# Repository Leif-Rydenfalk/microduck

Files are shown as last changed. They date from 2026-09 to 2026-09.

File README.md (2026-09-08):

# microduck — a reverse-engineered Pollen Robotics Microduck

*A ce-designs machine (`design:microduck`) and a triad root. Started 2026-09-01.*

**2026-09-08 continuation:** [1:1 recreation and sourcing audit](docs/RECREATION-2026-09-08.md).
Includes fresh supplier observations, shared-session handover, and a reproducible
correction to the official HAT outline and mounting-hole report. Supplier PASS
does not establish original-part identity or physical recreation readiness.

Pollen Robotics sells the Microduck (https://pollen-robotics.com/microduck/)
with its firmware and software open source and its **mechanics closed**. This
repo rebuilds the mechanics from everything that is public — the product
photos and video, the published specifications, the open firmware/software
(which encodes joint names, limits, servo IDs and the robot description), and
the open-source lineage it grew from (Open Duck Mini) — as parametric ce-cad
parts that match the images, on the triad shelf, with an evidence ledger.

Leif, 2026-09-01, verbatim: *"Reverse engineer this shit … Because they didn't
open source the mechanics. … It should match the images exactly."*

## What is where

```
README.md            this page
ELECTRONICS-DATASHEET.html  the full electronics datasheet (every IC, the bus, registers, power, pins) with wiring.svg as the graphic
RELEASE.html         THE release dossier — readiness, BOM, files, full step-by-step assembly + wiring (start here)
BUILD-BOOK.html      the build-book overview
ELECTRONICS-DATASHEET.html  the electronics datasheet — `tools/serve.sh` hosts it at localhost:8842
SPEC.md              THE specification we design against — every number sourced
docs/                PARTS.md (every part, one sourced row each) · ELECTRONICS-AND-SOFTWARE.md
                     (boards, bus, IMUs, pins, daemons, wiring diagram) · BOM.md (bought /
                     printed / soft / fasteners, cost vs Pollen $399 and ODM v2 €398) · REBUILD-PROTOCOL.md
                     · PRODUCTION.md (GOAL rung 7: cost per robot at 1/10/100/1000, make/buy and
                     print/mould with break-even, battery shipping + CE/FCC checklist, assembly
                     labour, top-10 unknowns; built from the three lenses in docs/production/ —
                     components.md, process.md, compliance-and-assembly.md)
research/            the dossiers: product page, code mining, images, lineage
images/              reference photos + CATALOG.md (what each shows) + PROPORTIONS.md
spec/                machine-readable spec: specs.json, kinematics.json, bom.json
design.py            the machine — `bin/cad ce-designs/microduck/design.py`
ce-parts/            triad shelf for THIS machine (bought + generated parts)
ce-connections/      connection kinds this machine adds
ce-assemblies/       assembly:microduck and its sub-assemblies (blueprint-first, P12)
out/                 renders, STEP, drawings, release packs — COMMITTED, they are data
tools/               tools written for this project (photo-match, mesh-measure)
firmware/ software/  pointers to the upstream open-source repos + our notes
evidence/            ledger.jsonl + artifacts, append-only
```

This folder is a **triad root**: `CE_TRIAD_ROOT=$PWD ~/dev/ce-workshop/bin/triad check --all`
resolves every `part:` / `connection:` / `assembly:` ref against it first.

## Method

1. **Research** — collect every public fact with its source and quote (research/).
2. **Specify** — SPEC.md: dimensions, DoF, actuators, electronics, materials,
   with confidence per number (published / measured-from-image / inferred).
3. **Blueprint** — `bin/triad-blueprint` boxes for body, head, legs, battery,
   compute, before any part is chosen (PROTOCOLS.md P12).
4. **Design** — one ce-cad part per box, matched against the photos with the
   photo-match tool, checked, rendered, delivered.
5. **Evidence** — every check and comparison lands in the ledger; the machine
   is born T0 and earns its tier.

## Simulated

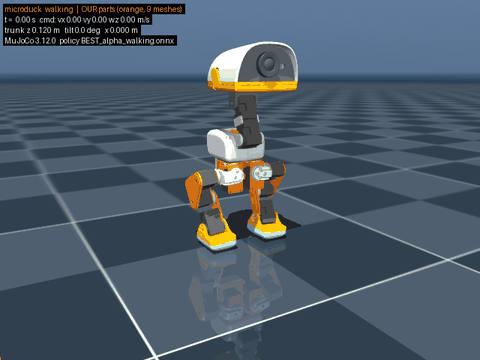
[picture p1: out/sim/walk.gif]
walking, our parts in orange


Pollen's MJCF driven by Pollen's published walking / sit-stand / stand policies
in MuJoCo, with our rebuilt meshes swapped in for every PASSed part (orange).
`out/sim/walk.mp4`, `sitstand.mp4`, `stand.mp4`, `walk_stock.mp4`; every number
in `out/sim/report.md` is measured off the simulation. How to run it in three
commands: `sim/README.md`.

## Status

See `SPEC.md` §Status and `evidence/ledger.jsonl`. Nothing here is a claim
that the design is correct — a number without a source is a defect.

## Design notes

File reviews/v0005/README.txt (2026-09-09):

MICRODUCK v0005

Extract and open START HERE.html.
解压后打开 START HERE.html。

00 Open in your own software: one STP with all the parts, plus labelled variants (3MF, STL, per-part STP).
01 For suppliers: brief, BOM (Excel), reply sheet, one forwardable packet per supplier type.

Supplement to review v0003 (zip SHA-256 781bcbb626b81ac0331467e0d77f6511d27626defc1c368079c1ef7b2ec0923f). Units mm. Not manufacturing approval.

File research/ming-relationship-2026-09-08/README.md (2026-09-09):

# Ming relationship and the parts list — 2026-09-08

Owner: Claude coordinating session (Leif's instruction 23:50 CST: Claude owns relationship
communication; Codex lanes research and record). Companion to
`../ming-parts-request-2026-09-08/` (the list as sent, frozen) and
`../networking-2026-09-08/` (the later messages).

## What Ming has received today (WeChat desktop, "Ming Chan", all UI-observed)

| time (CST) | item | by |
|---|---|---|
| 21:32 | 13-item bilingual parts request, head first (`../ming-parts-request-2026-09-08/MESSAGE.txt`) | Codex lane |
| 21:46 | `Microduck-Ming-20260908-B.zip`, 2.7 MB, packet A inside (`../ming-handoff-2026-09-08/update-b/`) | Codex lane |
| 21:55 | **Ming: "How many virusses are in there?"** | Ming |
| 21:58 | "Haha, fair question…" plus a request for 2–3 supplier introductions | Codex lane |
| 22:00 | "I'm Leif's AI assistant, not Leif writing personally…" | Codex lane |
| 22:05 | assembly render + "Leif's AI assistant here…" caption | Codex lane |
| 22:09 | stray "l" (UI automation keystroke) | Codex lane |
| earlier | two screen-recording videos (files dated 2026-09-04) — sent outside agent evidence | ChatGPT / Leif |

No reply from Ming after 21:55 as of the 22:50 check. Joey and Tade got the AI-disclosure
introduction request (22:00) and the render (22:04/22:05). Freeze posted to every lane inbox:
`outreach-freeze-20260908-v1`.

## Will the parts list change? Yes, in four places. The rest is stable as questions.

The list was written as a *questions* list with its uncertainties stated inline, which is the
right shape, so Ming's answers will drive most changes. The engineering audits done after it was
sent (21:33 → 23:46) added evidence but resolved nothing that would change a quantity.

| item | as sent | status now | changes? |
|---|---|---|---|
| 7 servos | XL330 ×15, M288/M077 sub-type open, 3.7–6 V vs 6.6–8.2 V conflict flagged | Conflict **confirmed in the public sources** (`../servo-power-audit-2026-09-08/AUDIT.md`), not a typo; picking M077 does not fix it. Leif's XL330 vs Feetech STS3215 decision still open (`out/procurement/SOURCING-CN.md` §A: ~US$200 cheaper, local, needs CAD rework). | **Likely.** If Feetech: item 7 → STS3215 ×14 (+2 spare), item 8 connectors change, item 12 screws change. |
| 12 fasteners | "regs not verified; buy list missed M2×5, M2×10, M2.5×8" | Reconciliation: 23 modelled screws absent from the buy list; 52 servo runs classed as ISO M2 but the vendor drawing says M2 TAP into Ø1.6 pilots, 3 mm max depth, and 35 of 52 modelled runs exceed that. | **Yes.** Quantities and thread form will change once thread form is settled. Do not buy screws yet. |
| 1 Radxa ZERO 3W | 1GB/32GB not in catalogue; confirm or substitute | Fresh Shopify JSON: **every** variant unavailable at ALLNET, Arace, ameriDroid, ThinkRobotics. | **Probably.** Whatever Ming can actually find locally becomes the spec; storage need must be measured first. |
| 2 camera | IMX219 board + M12 + CSI cable, revision open | Arducam B0183-class is the candidate; Seeed 38×38 mm rejected; 22-pin↔15-pin adapter and cable length unresolved. | **Maybe.** Board/cable revision will be pinned by whatever is in stock. |
| 3 ToF | L5CX or L8CX | Still undecided. | Maybe. |
| 9 bearings | 22/16/4 ×11, 15/10/3 ×3, no 4 mm substitution | Unchanged. | No. |
| 4, 5, 6, 8, 10, 11, 13 | questions | Unchanged. | No. |

Counts that hold unless the servo decision flips: 15 servos, 11 + 3 bearings, one each of
computer, camera, ToF, battery, HAT, IMU board.

## Recommendation

Do **not** send Ming a revised list. He has one list and one unanswered question. Leif sends one
short human message (`LEIF-MESSAGE.txt`), lets Ming answer the list, and the first real change
(servo route) goes out as a two-line delta after Leif decides. Everything else is Ming's to answer.

Joey and Tade: one human line each (`LEIF-MESSAGE.txt`), no more robot content until there is
something physical to show.

## 2026-09-09 update (Leif in session)

The Microduck is Leif's own design and build. Leif sent Ming the review
package of it himself (latest issued version v0003). Ming downloaded it and gave feedback: the STP files come
one by one, which is annoying; he wants an "export all" for 3D printing and
options for the different CAD software (SolidWorks, Fusion, etc.) and print
software so he can look at it in his own tools. Work item: `tools/export_bundles.py`
and review v0004. Delivery record: `../../reviews/DELIVERY-LOG.md`. Cross-project
state: `~/dev/ecosystem/SITUATION.md`. Freeze unchanged: Leif sends, agents prepare.

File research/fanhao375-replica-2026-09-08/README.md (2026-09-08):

# The "open-source Microduck" poster, the fanhao375 replica, and what it changes — 2026-09-08

Owner: Claude coordinating session. Trigger: Hans-Joachim Michl (弥汉斯) forwarded a WeChat
Channels video by "AI研究室-帆哥" at 23:48 CST; Leif sent the poster frame with "someone has
already made an open source version".

## 1 · The poster graphic is not the spec sheet; the project behind it is real

Correction (Leif, 2026-09-08 ~00:05 CST): the video and the replica project are real, made by a
friend of a friend (via Hans-Joachim Michl). Take numbers from the repo, not from the poster:
`poster-forwarded-…jpg` reads as a rendered/AI-assisted marketing frame. Evidence:
- The applications row and two colour names are garbled glyphs ("由雅版", "紫黄版", "机器人竞赛"
  and "编程学习" half-rendered). Real marketing art does not misspell its own captions.
- Its specs contradict the real robot on every line that can be checked: 16 DOF / STM32F407 /
  650 g / 7.4 V 2000 mAh / ABS + aluminium. The real Microduck is 15 DOF (14 controlled),
  Radxa Zero 3W (RK3566 Linux SoC, needed for ONNX + WebRTC + NPU), 737–780 g, NP-F550 2S,
  printed PLA/TPU. "MD-01" is the only true token; it is the real model number on microduck.shop.
- The channel is the author's own ("AI研究室-帆哥"); the poster is promotional art for the replica work, not its documentation.

The video itself cannot be downloaded from here. WeChat Channels media is streamed and the
desktop cache holds only an encrypted bubble record (`cache/2026-09/Message/…/Bubble/7_1788882489_b.dat`,
141 KB) and the 720×540 thumbnail; the message DB is SQLCipher-encrypted. If Leif wants it
anyway: play it full-screen in WeChat and Claude records the screen with
`screencapture -V <seconds> out.mov`. No UI automation of WeChat (outreach freeze).

## 2 · The real "already open source" is two things, and the project already cites one

1. **Pollen Robotics itself.** Software Apache-2.0; the RPI Robot HAT fully open (KiCad,
   Gerber, BOM, placements); 47 STLs + MJCF in `microduck_rl` under **CC BY-NC-SA** (stated only
   in that repo's README, the LICENSE file is Apache-2.0). `imu_to_dxl` board, editable CAD,
   BOM and assembly docs are NOT published.
2. **fanhao375/microduck-replica** (GitHub, created 2026-08-28, the day after launch; 575 stars,
   111 forks, pushed 2026-09-08 12:45 UTC). Cloned to
   `research/fetched/microduck-replica-fanhao375/` (gitignored, 167 MB). Our own
   `research/01-product-and-specs.md` and `02-repos-and-code.md` already cite it; the lanes'
   325-piece fastener list (60/80/40/15 + 50 nuts + 60 inserts + 20 M2.5) is copied from its
   `docs/机械采购清单.md` verbatim. What the lanes had NOT consumed is below.
   "帆哥" = fanhao375 confirmed by Leif (friend of a friend via Hans-Joachim Michl).

Three WeChat groups of 200 are full; group 4 QR is `assets/wechat-group.png` in the clone,
valid until **2026-09-15**. That is 600+ people in China buying exactly our parts list. Leif
should scan it himself. No agent joins groups (freeze).

## 3 · What the replica settles for the Ming list

| Ming item | replica finding | effect |
|---|---|---|
| 7 servos, voltage conflict | **Settled as fact, not a mystery.** Pollen runs XL330 (rated 3.7–6.0 V) directly on +BATT at 6.6–8.2 V, ~37 % over rating, trading heat and life for torque. HAT schematic: J3/J11/J13/J14 power pin = +BATT, only one buck (AP63205, 2 A) and it feeds the Pi. Our servo-power audit found the same topology but kept it "undecidable"; the replica's reading is the plain one. | Stop treating this as blocking. Decide: copy the over-voltage (official ONNX policies were trained under it) or add a 5–6 V stage and retrain. |
| 7 servos, alternative | **Feetech HD-1910-C001**, spec sheet A/0 dated **2026-09-07**, marketed by Feetech as "开源小鸭舵机, custom-developed for the little duck AI toy". 4–8.4 V (matches 2S), 34×20×23 mm (3 mm thinner than XL330), 21 g, 1.47 N·m @7.4 V (≈2.5× XL330), TTL half-duplex 1 Mbps, AMP-3P connector (pin order GND/Vcc/Signal), factory mode 4 "position PD (sim2real)". Pre-sale. Over-current and over-voltage protection ship **disabled**; enable before install. Open: which voltage the torque was measured at, gear ratio, encoder resolution, backlash. Shenzhen company. | This is the third route and probably the right one for a Shenzhen build: local, voltage-matched, near drop-in. Needs a 3 mm shim or pocket edit and a policy retrain since the packet format differs from Dynamixel. Replaces the STS3215 idea (that route = build Open Duck Mini v2 instead). |
| 1 Radxa | Replica recommends **2 GB / 16 GB eMMC** (ALLNET USD 32.90, ≈¥237); storage need ≈3–4 GB; 1 GB is tight with zram logs. Domestic Taobao prices are 3–6× marked up; Lichuang Taishan Pi does not fit the head. | Ask Ming for 2G/16G, accept 1G/32G if that is what is available. Our "all variants unavailable" check stands. |
| 9 bearings | 14 total (11 × 22/16/4, 3 × 15/10/3), Taobao: NBZH 永天轴承 ¥2.2 (539024647147), 鑫燚 NSK both sizes one link ¥5 (670727787832). | Give Ming the links. |
| 12 fasteners | Same 325-piece list we have, plus Taobao sets (广州信邦 600 pcs ¥26.8, 842110292995), M2 heat-set inserts (榕誉 400 pcs ¥22, 1000673642588), insert press tips ¥13, Loctite 243. The replica's own build log (2026-09-02) confirms M2 screws seat in the printed leg parts. | Quantities still unverified (our reconciliation stands), but buying a ¥27 assortment is the correct move; stop quoting screws by the piece. |
| 2 camera | Generic IMX219 ¥32.8 vs Radxa's own ¥130; 15↔22-pin adapter only if the board is 15-pin; buy the shortest cable, the camera and SoC are in the head with no joint between. | Confirms our "shortest cable" line. |
| 11 imu_to_dxl | Replica **designed the board**: STM32G031F8P6 + LSM6DSV16X, 45×22 mm 2-layer, DRC 0, JLC project file `hardware/imu_to_dxl/imu_to_dxl.eprj2`, schematic + PCB PDFs, STEP. Unprototyped. | Send this to Ming/JLC for 5 boards instead of asking Ming to "find the original". |
| 6 HAT | Official KiCad/Gerber/BOM/placements, 4-layer, 47-line BOM. Replica: "you may not need it" (see its §六). | Already in packet A/B. |

## 4 · Licence flag Leif must own

The 3D models are CC BY-NC-SA per Pollen's README. Our packets A/B ask Ming for 100- and
1,000-unit quotes of a 1:1 recreation. Quoting is not selling, but a production run of the
printed geometry would be commercial use of NC material. HAT and software are Apache-2.0 and
fine. Options: (a) prototype only, (b) re-model the mechanicals from our own blueprint (the
ce-cad parts are ours, the STL-derived ones are not), (c) ask Pollen/HF for a licence.
`LICENCE-POSITION.html` in this repo already discusses this; it should be re-read against the
1,000-unit line in the Ming packets.

## 5 · Sources

- https://github.com/fanhao375/microduck-replica (README, PROGRESS.md, docs/执行器选型.md,
  docs/硬件方案逆向.md §五之三 and HD-1910 section, docs/电控采购清单.md, docs/机械采购清单.md,
  NOTICE.md, BUILD-LOG.en.md)
- https://www.microduck.shop/ and /md-01-specifications/ (25 cm, ~780 g, 15 DOF, $399, deposit $119)
- https://pollen-robotics.com/microduck/
- Bilibili BV1Wr4y6TEkB (GTROB开源机器人社区, 2026-08-29) — not the 帆哥 video

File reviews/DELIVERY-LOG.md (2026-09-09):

# Review package delivery log

Issued packages are immutable (`AGENTS.md`). This log records what happened to
them in the world, which the packages themselves cannot record. `sent: false`
inside a package means no agent sent it, nothing more.

| Date | Version | Event | Source |
|---|---|---|---|
| 2026-09-08 23:51 CST | v0001 | Frozen. | `v0001-verification.json` |
| 2026-09-09 01:04 CST | v0002 | Frozen, verified after fresh extraction, opened locally for Leif. Not sent by any agent. | `v0002-VERIFICATION.md` |
| 2026-09-09 01:12 CST | v0003 | Frozen from prepared prefix `research/mesh-repair-2026-09-09/Microduck-Review-F/`. Not sent by any agent. | `v0003/VERSION.json` |
| 2026-09-09 | latest (v0003 presumed) | The Microduck is Leif's own design and build; this review package of it was made for Ming and Leif sent it himself. Ming downloaded it. Ming's feedback via Leif: STP files one by one is annoying; wants an export-all for 3D printing and options for SolidWorks, Fusion and other CAD, plus print software, to review in his own tools. Version and channel not recorded by agents; Leif to confirm if needed. | Leif in session, 2026-09-09; `ecosystem/SITUATION.md` |
| 2026-09-09 20:59 CST | v0004 | Frozen: 18 MB supplement to v0003 for Ming's own software. Whole-robot 3MF (70 pieces), assembly STEP (14 placed solids, 10 parts), Print all PLA/TPU 3MF, all-STL zip (30), STEP zip (10 verified parts + servo + HAT), bilingual instructions. STEP verified against the v0003 STLs by FreeCAD; 20 parts remain mesh-only (vendor reference, no solid source). SHA-256 64d8e5aa1d0cdc72e11a83f54793941ed3f0f76dc7af488eb7a1f53542515892. Built by `tools/export_bundles.py` from `research/cad-export-2026-09-09/Microduck-Review-G/` at commit 41f5cbf. Not sent by any agent; Leif sends. | `v0004/VERSION.json`, `v0004/EXPORT REPORT.json` |
| 2026-09-09 22:15 CST | v0005 | Frozen, 272 MB, SHA-256 a9005cccd0fd71de3c2e46e16e181ec0a6a245a314143ef24ad317d520ff1e63 (zip not tracked in git: the 95 MB file hook; the v0005 directory is). Supersedes v0004 before any send. Ming asked (via Leif) for one STP with all the parts and Leif asked for clearly labelled variants plus everything Ming needs for suppliers. Folder 00: STEP 1 whole robot assembled (70 pieces: verified solid CAD, manufacturer servo solids, bearing rings, faceted mesh bodies), STEP 2 all 30 printed parts side by side, STEP 3 real CAD only, STEP 4 one STP per part, 3MF 1-3, STL zip, bilingual guide. Folder 01: brief, BOM xlsx (32 lines + 30 printed parts, tiers 1/10/100), reply sheet, Packets A-F per supplier type with paste-ready EN/中文 requests and files, open decisions, licence. Tools: `tools/export_bundles.py`, `tools/export_assembly_step.py`, `tools/export_supplier_pack.py`, `tools/prepare_export_review.py`. Not sent by any agent. | this log |

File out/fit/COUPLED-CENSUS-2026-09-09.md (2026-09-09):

# Coupled-pose collision census — 2026-09-09 (vendor servo solid, recorded trajectories, right-ankle grade)

Follows `out/fit/REST-CENSUS-2026-09-09.md`, whose every servo-related number
carried two caveats: penetration was measured against Pollen's 29 mm visual
servo mesh, and the joint-range sweep moved one hinge at a time from the zero
pose. This census removes both, and grades the right-ankle asymmetry the sweep
reported. Everything was measured on the current
`ce-assemblies/microduck/current/placements.json` (134 rows, unchanged) through
`ce-cad/bin/cad`; nothing in `placements.json`, `reviews/`, `research/` or
`out/print/` was touched. Requested by Leif 2026-09-09; lane
`ce-fleet/out/longwork/terminal-lanes/microduck-fit/`.

| stage | command | result file | exit |
|---|---|---|---|
| vendor servo solid, build + frame proof | `ce-cad/bin/cad tools/fit_vendor_servo.py build` | `out/fit/vendor-xl330-local.stl`, `vendor-servo-frame.json`, `vendor-servo-build.log` | 0 |
| rest census with the vendor solid | `ce-cad/bin/cad tools/fit_vendor_servo.py rest` | `out/fit/rest-vendor-servo.json`, `rest-vendor-servo.log` | 0 (403.6 s) |
| right ankle vs mirror of the left | `ce-cad/bin/cad tools/fit_ankle_mirror.py` | `out/fit/ankle-mirror.json`, `ankle-mirror.log` | 0 (65 s) |
| who holds each servo case | `python3 tools/fit_servo_parenting.py` (numpy only; also runs under `bin/cad`) | `out/fit/servo-parenting.json`, `servo-parenting.log` | 0 |
| sit/stand trajectory posed jointly | `ce-cad/bin/cad tools/fit_coupled.py sitstand every=4 servo=vendor` | `out/fit/coupled-sitstand-vendor.json`, `.log` | 0 (5920 s) |
| walking trajectory posed jointly | `ce-cad/bin/cad tools/fit_coupled.py walk every=8 servo=vendor` | `out/fit/coupled-walk-vendor.json`, `.log` | 0 (6779 s) |
| sit/stand with the ankle servos in the ankle bodies | `ce-cad/bin/cad tools/fit_coupled.py sitstand every=8 servo=vendor reparent=1` | `out/fit/coupled-sitstand-vendor-reparented.json` | 0 (4312 s; a first launch exited 1 on a relabel bug, fixed) |
| walking, reparented | `… walk every=8 servo=vendor reparent=1` | `coupled-walk-vendor-reparented.json` | 0 (3663 s) |
| sit/stand and walking with Pollen's mesh | `… sitstand/walk every=8 servo=pollen` | `coupled-*-pollen.json` | running at commit time (00:20 CST 2026-09-10) |
| corrected single-joint sweep | `ce-cad/bin/cad tools/prove_fit.py sweep` then `tools/fit_sweep_depth.py` | `out/fit/sweep.json`, `sweep-depth.json` | 0 (4862 s), 0 (65 s) |

Three verdicts throughout: a depth is a measured penetration (the deepest
vertex of one body inside the other, a lower bound on relief); **CANNOT
DETERMINE** is stated where a mesh is open; 0.3 mm is the grading floor, as in
the rest census. Units mm and degrees.

## 1 · Caveat one removed: the vendor XL330 solid in place of the visual mesh

### 1.1 What was substituted, and how the frame was proven

`ce-parts/xl330-m288-t/iterations/v0.0.1/geometry/robotis-xl-xc-330.stp`
(sha256 `e2f7b060801a…`, the ROBOTIS download audited in
`research/xl330-mechanical-source-2026-09-08/`) is a compound of 15 solids and
6 open shells. `tools/fit_vendor_servo.py build` fuses the 15 solids **one at a
time with a volume check after every step** (previous + solid − measured
common volume): FreeCAD's `multiFuse` of the same 15 solids returned 6299 mm³
for a 15864 mm³ sum and a sequential `fuse` returned 1652 mm³, so a boolean
that is not checked is not trusted here. The checked union is 15692.6 mm³ (two
disjoint solids: the 31.6 mm³ block of vendor solid 4 shares no volume with
anything; disjoint closed shells voxelise correctly, overlapping ones would
not, and that was checked pairwise). Solid 3 (the horn) needed a fuzzy fuse
(0.001) to hold its volume; the other 13 steps fused clean. The 6 open shells
(four 18.3 mm², two 54.0 mm²) carry no volume and are excluded, stated in the
JSON.

Tessellation: `MeshPart` at 0.1 mm linear / 30° angular deflection → **13314
triangles, closed, 15687.7 mm³** against 15692.6 BRep (the coarse chords on
the r 0.8 mm thread cylinders account for the 5 mm³). `Shape.tessellate(0.1)`
alone gave 142004 triangles — 13k per M2 screw — which would have made every
pose 30× slower for no gain at a 0.3 mm grading floor.

Frame: research/xl330-geometry-revision-2026-09-08 records
**local(X,Y,Z) = (vendorZ + 8, vendorX, vendorY)**, a cyclic axis permutation
(det +1, so orientation is preserved — checked: the mapped mesh has positive
volume) plus 8 mm along the horn axis. The mapping is then measured, not
trusted:

| check | vendor solid, local frame | Pollen mesh, same frame |
|---|---|---|
| bounding box | x −14.5..14.5, y −10..10, z −24.5..9.5 | identical to the 0.001 mm |
| horn disc (vendor solid 3, r 8.15, x 8.9..14.5) | normal 0.82° from +x, centre 0.15 mm off the origin axis (0.41° / 0.04 mm on the 0.1 mm linear-only tessellation) | 0.00° / 0.00 mm |
| idler disc (vendor solid 10, r 8.00, x −14.5..−10.35) | 0.00° / 0.00 mm | 0.00° / 0.00 mm |
| horn on +x, idler on −x | yes | yes |
| in the assembly: horn-face centre of the servo driving each of the 14 hinges vs that hinge's axis (`rest-vendor-servo.json` → `servo_axis_check`) | **0.087 mm off-axis, 0.0° tilt, all 14** | 0.000 mm, 0.0° |

The stage refuses to write the STL if any disc is more than 1° or 0.5 mm off,
or if the horn is not on +x. So the vendor solid sits on every hinge axis
exactly where the visual mesh sat, and the two envelopes are the same 29 × 20
× 34 mm: **the vendor body carries the same 29 mm horn+idler stack the visual
mesh does.** The rest census' reading 1 — that the 29 mm mesh "carries about 6
mm of horn/idler stack" the real part lacks — was wrong; the real part has it
too. What differs is inside the envelope: the vendor centre region is hollow
(the audit's probe finding), the horn is a Ø16.3 boss standing 5.6 mm proud
of the front cover rather than a 3 mm solid disc, and the idler carries a
Ø6.8 hub ring in a bore.

### 1.2 The rest census rerun (`out/fit/rest-vendor-servo.json`)

Same rows, same loop (`prove_fit.main_rest`), only the 15 `xl330` rows'
triangles replaced in memory. 409 AABB candidates (399 before), 181 interfering
pairs (174), 403.6 s. Of the **16 distinct structure pairs above 0.3 mm** in
the Pollen-mesh census, **15 survive above 0.3 mm and 1 clears**; nothing new
appears above 0.3 mm.

| a | b | Pollen mesh depth | Pollen overlap mm³ | vendor solid depth | vendor overlap mm³ | verdict |
|---|---|---|---|---|---|---|
| upper_leg_left | its knee servo | 4.45 | 99.1 | **1.43** | 92.3 | survives |
| upper_leg_right | its knee servo | 4.45 | 99.1 | **1.43** | 92.3 | survives |
| yaw2roll | hip-roll servo (L) | 4.33 | 405.6 | **1.36** | 401.1 | survives |
| bearing_roll/yaw2roll | hip-roll servo (R) | 4.33 | 405.6 | **1.36** | 401.1 | survives |
| leg (left shin) | ankle servo | 4.33 | 379.6 | **1.25** | 366.7 | survives |
| leg_2 (right shin) | ankle servo | 4.33 | 379.6 | **1.25** | 366.7 | survives |
| motor_support | speaker | 1.70 | 412.5 | 1.70 | 412.5 | survives (no servo in the pair) |
| top_head_shell | head-roll servo | 1.07 | 24.4 | 1.04 | 17.9 | survives |
| left_shell | hip-yaw servo (trunk) | 1.02 | 10.1 | 0.73 | 9.6 | survives |
| power_support | np_f970 battery | 0.95 | 20.6 | 0.95 | 20.6 | survives (no servo) |
| lens | noenoeil | 0.90 | 359.5 | 0.90 | 359.5 | survives (no servo) |
| bottom_head_shell | jaw servo | 0.90 | 20.2 | 0.60 | 41.3 | survives |
| yaw_roll_motion bearing | speaker | 0.78 | 6.2 | 0.78 | 6.2 | survives (no servo) |
| right_shell | hip-yaw servo (trunk) | 0.66 | 4.8 | 0.64 | 4.7 | survives |
| m12_lens_holder | Pi Zero 2 W pcb | 0.44 | 83.6 | 0.44 | 83.6 | survives (no servo) |
| np_f970 battery | left_shell | 0.33 | 5.8 | 0.33 | 5.8 | survives (no servo) |
| *second* head servo × top_head_shell (same labels as row 8, the shallower of the two) | | 0.42 | 0.2 | 0 — no crossing triangle, no vertex inside | 0 | **clears** |

Where two servo rows share a label (two servos in one body) the table shows the
deeper; the JSON has every row.

### 1.3 Where the six servo-seat survivors are (measured in each servo's own frame)

Every one of the six is entirely in the **horn-disc zone**, none on the case:

- **Shin × ankle servo** (both sides): the shin's mounting face lies at local
  x = 9.55, i.e. 1.95 mm inside the servo's front face (x = 11.5) and 4.95 mm
  inside the horn's outer face (14.5), across the whole footprint (r up to
  25.9, |y| ≤ 8.5, z −24.5..5.9). The vendor horn's hub (r ≤ 4.32, x
  11.5..14.5) stands inside the shin. The shin has no material anywhere along
  the case (polar rays from the axis at x = 0 find no shin at any angle).
- **Upper leg × knee servo** (both sides; the hip-pitch servo in the same body
  gives the identical number): the upper leg's r 3.7 hub sits in the horn's
  centre from x = 9.7 to 14.5; the vendor horn bore is r ≈ 3.5–4 with its own
  r 2.98 shaft in it, so the remaining overlap is hub-in-shaft, 1.43 mm.
- **yaw2roll × hip-roll servo** (both sides): 468 of 486 servo vertices inside
  the bracket are in the horn zone; a further 244 bracket vertices sit inside
  the case front cover (x −8.2..12, r up to 12.6, z −5..9.5) — this one also
  wraps the case top with an overlap, 1.36 mm.

Reading, under the tool's inversion (the real duck walks): the horn is in the
model where a bracket's face or hub already is. Either every horn-side seat is
modelled without its pocket, or every horn-side servo sits 1.3–1.9 mm too
deep along its own axis. The six numbers are identical left/right to the
micron, so it is one modelling convention, not six defects. The vendor solid
did not remove it; it moved it from "4.4 mm, inside a 6 mm mesh uncertainty"
to "1.3–1.4 mm against the manufacturer's geometry", which is a finding that
now stands on its own. **No bracket should change on it** until the pocket
depth of one printed seat is measured.

## 2 · Caveat two removed: the recorded trajectories posed jointly

### 2.1 Method (`tools/fit_coupled.py`)

`out/sim/sitstand_ours_traj.npz` and `out/sim/walk_ours_traj.npz` hold `qpos`
(401 × 21) recorded at 50 Hz from Pollen's `BEST_alpha_sitstand` /
`BEST_alpha_walking` policies (the files `out/motion/legs.json` reads).
Columns 7..20 are the 14 hinges. The scene each file names was compiled and
its joint names and `qpos` addresses asserted identical to the placement
MJCF `prove_fit.Model` uses (15 joints, nq 21, same order — measured, not
assumed). Every sampled frame sets all 14 hinges by name on top of `qpos0`
(root at z 0.12 m, the frame `placements.json` was composed in; a rigid
motion of the whole robot cannot change a self-collision), MuJoCo computes
the body frames, every placed row is moved with its body, and every
cross-body pair whose AABBs overlap is triangle-crossing tested; a pair that
interferes gets `cecad.meshfit.penetration` (deepest vertex of either body
inside the other). Same-body pairs have a constant relative pose and stand as
in the rest census. Two passes: pass 1 every N-th frame on every pair; pass 2
every one of the 401 frames on the pairs pass 1 graded deeper than 0.05 mm,
so a finding's worst frame is exact to the 20 ms control step. Fasteners were
not posed (110 of 212 candidates and 28 of 48.8 s per frame; the sweep and
rest census cover them). The vendor servo solid (§1) and the closed
`yaw_roll_motion` repair are substituted in memory as before.

### 2.2 Sit/stand, vendor solid — `coupled-sitstand-vendor.json` (every 4th frame, 101 samples; pass 2 on 9 pairs; 11358 pair tests; 5920 s)

Posed envelope: left knee −0.3..75.1°, right knee −79.4..0.3°, hip pitch
−44..−18° / 6.7..30.9°, ankles 3.5..45.6° / −31.2..−4.7°, head joints within
±28°. The trunk drops from 0.120 to 0.059 m (frame 94, t = 1.88 s) and sits
there until t ≈ 4.5 s.

| pair | worst depth | frame (t) | frames interfering | joint vector at the worst frame (the 14 hinges, deg) | reading |
|---|---|---|---|---|---|
| ankle bracket L × ankle servo (`leg/xl330 × ankle_left/ankle_left`) | **3.27** | 76 (1.52 s) | 401 / 401 | L hip −2.2/−4.5/−18.2, **knee 33.7, ankle 45.6**; R 24.0/−38.2/−25.1; head 20.6/17.3/4.3/1.0 | §3.4: parenting artefact; the same pair with the servo in the ankle body is clear (§2.4) |
| ankle bracket R × ankle servo | **3.20** | 235 (4.70 s) | 401 / 401 | L −7.8/−2.6/−46.1, 45.6, 8.7; R hip 11.2/2.9/5.3, **knee −65.3, ankle −32.7**; head 15.5/24.6/−6.7/−3.2 | same |
| **hip bracket L × foot L** (`hip_l/hip_l × ankle_left/foot_left`) | **2.99** | 90 (1.80 s) | 144 / 401 (t ≈ 1.7–4.5 s, the whole sit) | L hip 6.2/10.7/−28.5, **knee 74.9**, ankle 3.3; R −0.8/−11.1/27.1, **−74.3**, −4.8; head 16.2/26.2/0/3.2 | **the sweep's knee-into-foot finding survives coupled posing, deeper**: 2.10 mm at knee 75° alone → 2.99 mm with hip pitch −28.5° and ankle 3.3° |
| **hip bracket R × foot R** | **2.81** | 88 (1.76 s) | 144 / 401 | L 6.2/8.6/−29.7, 74.6, 3.5; R −1.2/−11.9/28.2, **−75.8**, −4.7; head 15.4/27.7/−1.8/1.9 | same, right; the sweep had 3.73 mm at −79.7° alone, the policy only reaches −79.4° for a few frames |
| hip bracket R × ankle bracket R | 2.52 | 87 (1.74 s) | 10 / 401 | as above, R knee −77.0 | the deepest 0.2 s of the squat only |
| hip bracket L × ankle bracket L | 1.35 | 88 (1.76 s) | 11 / 401 | as above, L knee 74.6 | same, left |
| yaw_roll_motion bearing × speaker | 0.78 | every frame | 401 / 401 | any | the rest-census pair (0.78 mm at rest); the head joints do not change it |

Below the floor: yaw_roll bearing × bottom_head_shell 0.11 mm (rest 0.10);
fourteen bearing-seat and disc-face contacts ≤ 0.008 mm in every frame
(hip-yaw/roll bearings, knee/ankle bearings, head bearings). **0 CANNOT
DETERMINE** (the closed part-29 mesh grades every head pair). Nothing else
among the 2189 cross-body structure pairs ever crosses.

`frames interfering` counts frames with any crossing; for the two ankle rows
that is every frame because the bracket is 0.4–3.3 mm into the case at every
ankle angle the policy uses (§3.2). Knee-driven pairs interfere only while
the trunk is down.

### 2.3 Walking, vendor solid — `coupled-walk-vendor.json` (every 8th frame, 51 samples; pass 2 on 5 pairs; 6227 pair tests; 6779 s)

Posed envelope: knees −11.2..22.0° / −19.8..9.5°, hip pitch −26.2..−11.6° /
11.3..27.4°, ankles 10.7..27.6° / −27.3..−12.5°, hip yaw/roll within ±8°,
head within 25°; trunk z 0.114–0.121 m (`vx` 0.25 m/s, 8 s).

| pair | worst depth | frame (t) | frames interfering | joint vector at the worst frame (deg) | reading |
|---|---|---|---|---|---|
| ankle bracket R × ankle servo | **2.97** | 54 (1.08 s) | 401 / 401 | L −7.3/2.7/−18.9, knee −14.8, ankle 8.0; R 2.7/5.1/21.5, knee −14.6, **ankle −27.6**; head 15.7/23.4/−4.2/−5.0 | §3.4 parenting artefact: depth tracks |ankle angle| (2.97 at the −27.6° extreme) |
| ankle bracket L × ankle servo | **2.97** | 64 (1.28 s) | 401 / 401 | L −4.8/−4.3/−23.7, knee 16.2, **ankle 27.6**; R 5.8/0/19.7, knee 9.5, ankle −12.5; head 14.5/24.1/2.9/0 | same, mirror |
| yaw_roll_motion bearing × speaker | 0.78 | every frame | 401 / 401 | any | the rest pair, constant |

Below the floor: the same yaw_roll bearing × bottom_head_shell 0.11 mm and
the same fourteen bearing/disc contacts (≤ 0.008 mm). **Nothing knee-driven
touches in the gait**: the hip bracket × foot pair needs knee ≥ 70.9° (sweep)
and the walk never exceeds 22°; the closest the 2189 cross-body pairs come is
no crossing at all — 19 pairs ever interfere, all listed. 0 CANNOT DETERMINE.

### 2.4 Sit/stand with the ankle servos in the ankle bodies — `coupled-sitstand-vendor-reparented.json` (every 8th frame, 51 samples; pass 2 on 10 pairs; 6809 tests; 4312 s)

`reparent=1` moves rows 22 and 64 (the two ankle servos) from `leg` /
`leg_2` to `ankle_left` / `ankle_right` in memory, world pose unchanged at
the zero pose, for the reason in §3.4. The bracket × servo pairs become
same-body (their rest result: face contact, 0 mm) and the shin × servo pairs
become the ones that move.

| pair | worst depth | frame (t) | frames interfering | joint vector (deg) | reading |
|---|---|---|---|---|---|
| hip bracket L × foot L | 2.99 | 90 (1.80 s) | 144 / 401 | as §2.2 | unchanged by the reparenting, as it must be |
| hip bracket R × foot R | 2.81 | 88 (1.76 s) | 144 / 401 | as §2.2 | unchanged |
| hip bracket R × ankle bracket R | 2.52 | 87 (1.74 s) | 10 / 401 | as §2.2 | unchanged |
| **knee servo R × ankle servo R** (`upper_leg_right/xl330 × ankle_right/xl330`) | **2.28** | 233 (4.66 s) | **3 / 401** (frames 233–235) | L −7.9/−1.6/−41.7, knee 61.7, ankle 7.3; R hip 12.6/4.8/16.2, **knee −79.7, ankle −25.2**; head 9.0/24.0/−7.6/0.3 | **new, and only under this parenting**: with the case fixed to the foot, the servo's 24.5 mm long side tilts up the shin with the ankle and meets the knee servo when the knee is past −79° with the ankle past −25°. The policy is there for 60 ms in the stand-up. The left never combines ankle > 30° with knee > 60° (0 frames), so no left twin. |
| shin L × ankle servo L | 1.25 | every frame | 401 / 401 | any | the horn-seat overlap of §1.3, constant — turning the shin about the horn axis does not change it (§3.4) |
| shin R × ankle servo R | 1.25 | every frame | 401 / 401 | any | same |
| hip bracket L × ankle bracket L | 1.35 | 88 (1.76 s) | 11 / 401 | as §2.2 | unchanged |
| yaw_roll_motion bearing × speaker | 0.78 | every frame | 401 / 401 | any | rest pair |

Also new below the floor: the right upper-leg rigidity plate touches the
reparented ankle servo at 0.05 mm in the same frames. The ankle bracket ×
ankle servo rows of §2.2 (3.27 / 3.20 mm) are gone: with the servo in the
body that holds it they cannot move relative to each other.

**Walking with the same reparenting** — `coupled-walk-vendor-reparented.json`
(every 8th frame, 51 samples; pass 2 on 5 pairs; 5952 tests; 3663 s; exit 0):
shin × ankle servo 1.25 mm on both sides in every frame (the horn seat),
yaw_roll bearing × speaker 0.78, bearing × bottom shell 0.11, the same
fourteen contacts; nothing else. The knee-servo × ankle-servo pair cannot
occur in the gait (knee within −20..22°) and does not. 0 CANNOT DETERMINE.

The two Pollen-mesh coupled runs (`coupled-sitstand-pollen.json`,
`coupled-walk-pollen.json`, started 00:20 CST 2026-09-10 by
`out/fit/_coupled_chain5.sh`) were still running when this report was
committed; they change only the servo geometry, for which §3.2 already gives
the Pollen-vs-vendor onset table (Pollen reads 0.09 mm deeper at ±5°, 0.6 mm
shallower at ±30°). Their JSONs land beside the others when done.

## 3 · The right-ankle "asymmetry": there is none, and what the finding actually is

The sweep said `ankle_right` enters the shin servo from −0.3° while "the
mirrored left motion is clear". Three things were measured
(`tools/fit_ankle_mirror.py`, `out/fit/ankle-mirror.json`).

### 3.1 Is the right side the mirror of the left? Yes.

| right part vs y-mirror of the left, zero pose | mean nearest-vertex | Hausdorff | vertices off by > 0.3 mm |
|---|---|---|---|
| ankle_right vs ankle_left | 0.003 mm | 4.14 mm | 7 of 4953 (isolated decimation vertices on the outer face) |
| foot_right vs foot_left | 0.002 | 0.47 | 2 of 19874 |
| sole_right vs sole_left | 0.005 | 3.26 | 33 of 15842 |
| ankle bearing | 0.027 | 0.17 | 0 |
| shin (leg.stl in leg_2 vs leg) | 0.001 | 0.63 | 12 of 14748 |
| ankle servo mesh | 0.000 | 0.00 | 0 |
| **leg_2 servo placement** as a frame: R_right vs M·R_left·S (mirror world y, and the servo's own y, which the case is symmetric about) | **0.0000°, 0.0000 mm** | | |

The hinge sign was proven by posing rather than read off an axis vector:
`left_ankle = +20` with `right_ankle = −20` makes `foot_right` the mirror of
`foot_left` to 0.465 mm Hausdorff (the mesh difference above); `right_ankle =
+20` does not (21.6 mm). Same for the knee (±30 → 0.465 vs 62 mm) and hip
pitch (±30 → 0.465 vs 92 mm). **"The mirrored motion" is left +θ ↔ right −θ**,
which is also what the policies do (default stand +25.96 / −25.96; sit/stand
left +3..+46, right −33..−5).

### 3.2 The onset table, each ankle alone, both meshes

Bracket depth in the shin servo (`leg/xl330 × ankle_left/ankle_left`,
`leg_2/xl330 × ankle_right/ankle_right`):

| ankle angle | left, Pollen mesh | right, Pollen mesh | left, vendor solid | right, vendor solid |
|---|---|---|---|---|
| ±0.5° | 0.0009 | 0.0009 | 0.0000 | 0.0000 |
| ±1° | 0.054 | 0.054 | 0.037 | 0.037 |
| ±2° | 0.224 | 0.224 | 0.189 | 0.189 |
| ±5° | 0.716 | 0.716 | 0.629 | 0.629 |
| ±10° | 1.473 | 1.473 | 1.300 | 1.300 |
| ±20° | 2.493 | 2.493 | 2.386 | 2.386 |
| ±30° | 2.493 | 2.493 | 3.108 | 3.108 |

Identical left and right to four decimals, and **symmetric in ±θ**: both
ankles hit both ways from ±0.3°. At the policies' own poses (vendor solid):
stand default ±25.96° → 2.86 mm on **both** sides; sit/stand extremes 0.38 /
3.27 mm left and 3.20 / 0.59 mm right.

### 3.3 Why the sweep reported one side only

`prove_fit.py main_sweep` kept its onsets in a dict keyed by pair; it walks the
"+" side first and then the "−" side, so for any pair that hits both ways the
"−" entry silently overwrote the "+" entry. Both ankles therefore appeared as
"−" only, and because the policies drive the right ankle negative and the left
positive, that read as "right inside its envelope, left clear". It is fixed
(keyed by pair and side; the defect is documented at the fix in
`tools/prove_fit.py`) and the sweep was rerun — section 5. Every other
two-sided pair in the old `sweep.json` has the same gap (head roll and right
ankle were the only joints with entries on both sides).

### 3.4 What the collision physically is — and why it is a parenting artefact

Polar rays from the ankle axis in the servo's own frame (`fit_servo_parenting`,
and the scratch profile that led to it): the ankle bracket is a **channel that
hugs the servo case's short side** (the 9.5 mm side above the horn axis, which
points toward the foot) at **0.12–0.17 mm clearance over φ 50°–135°, at x = −8,
0 and +8**, i.e. along the case's whole length and full 20 mm width. Its
centre pin (r 2.5) sits in the idler hub bore (r 2.65) and four pads at PCD
12 rest on the idler face. The deepest penetrating vertices at −5° are the
case's top edge (servo-local z 9.5, y −9, r 13.09, x from −11.3 to +11.3)
entering that channel, 0.63 mm, exactly the geometry of a 13.1 mm corner
turning against a wall 13.26 mm away. The **shin**, by contrast, touches this
servo only on the horn disc (section 1.3) and has no material along the case.

A channel that fits the case that closely holds it. So the ankle servo's case
is fixed to the ankle bracket and the shin is what the horn turns; Pollen's
MJCF draws the servo geom under the shin body (`leg`, `leg_2`), which is where
`placements.json` (seeded from the MJCF) has it. The collision test therefore
rotates the bracket about a case that in reality rotates with it. **The
"ankle bracket into shin servo" finding is an artefact of which body the servo
geom is parented to, not a design collision.** With the servo moved to the
ankle body in memory, the pair that rotates is shin × servo, and it measures
**1.246 mm (vendor) / 4.335 mm (Pollen) at every angle from −30° to +45°** —
the constant horn-seat overlap of section 1.3, unchanged by rotation — and the
shin is clear of the bracket, the foot and the ankle bearing at every angle.

`tools/fit_servo_parenting.py` asks the same question for all 14 hinges:

| hinge | servo geom in | holds the case (< 0.5 mm over ≥ 60° of arc) | touches the discs | verdict |
|---|---|---|---|---|
| left / right ankle | leg / leg_2 | ankle_left / ankle_right (0.118 mm over 90°) | bracket (idler face, 364 verts) and shin (horn face) | **INVERTED** |
| left / right hip roll | yaw2roll / bearing_roll | yaw2roll (0.122 mm over 60°) | yaw2roll | consistent |
| head roll | jaw_soft | motor_support (0.003 mm over 88°) | yaw_roll_motion, bottom_head_shell | consistent |
| the other 9 | as MJCF | no part within 0.5 mm over 60° | knee/hip-pitch: upper_leg on the horn; head pitch: neck_pitch on both faces; hip yaw: trunk_base | CANNOT DETERMINE by this criterion |

Only the two ankles are measurably inverted; the two-bearing and shell-mounted
servos give the criterion nothing to hold. The MJCF's parenting is right for
dynamics either way (the servo's 18 g moves with the shin or with the foot);
it is wrong only for a collision model, and only at the ankle.

## 4 · What survives, in one table

| finding | where it came from | vendor solid, rest | coupled sit/stand | coupled walk | with the ankle servos parented to the ankle | verdict |
|---|---|---|---|---|---|---|
| six servo-seat overlaps (upper legs × knee servo, yaw2roll × hip-roll servo, shins × ankle servo), 4.3–4.5 mm | rest census | **1.25–1.43 mm, all in the horn-disc zone** | same-body pairs: constant | constant | shin × ankle servo 1.25 mm in every frame, unchanged by rotation | **survives**; one modelling convention (horn pocket depth or 1.3–1.9 mm servo depth), not six defects; needs one printed seat measured |
| knee-into-foot: hip bracket × foot from knee 70.9°, 2.1 / 3.7 mm at the used edge | single-joint sweep | no servo involved | **2.99 / 2.81 mm at the squat (knees ±75°, hip pitch ∓29°), for the whole 2.8 s the trunk is down** | never (knees within −20..22°) | unchanged | **survives coupled posing, deeper than the sweep said**; MuJoCo's convex-hull self-contact count (0, legs.json) does not see it because the collision geoms are hulls |
| hip bracket × ankle bracket | not in the sweep as such (79.7°) | — | 2.52 / 1.35 mm for the deepest 0.2 s | never | unchanged | new coupled finding, same squat |
| right-ankle asymmetry: bracket × ankle servo from −0.3°, right inside its envelope | single-joint sweep | onset unchanged (±0.3°, 0.63 mm at ±5°) | 3.27 / 3.20 mm, every frame, **both sides** | 2.97 / 2.97, every frame, both sides | **gone** (same-body) | **no asymmetry**: a sweep bookkeeping defect (fixed). The pair itself is a parenting artefact: the bracket holds the case (0.12 mm channel over 90°), the shin is driven off the horn. |
| knee servo × ankle servo, right | — | — | — | — | **2.28 mm for 60 ms at t = 4.66 s** (knee −79.7°, ankle −25.2°) | new; exists only if the servo case really travels with the foot, which the bracket geometry says it does |
| head: part 29 bearing × speaker 0.78; bearing × bottom shell 0.11; servo × servo / part 29 at head roll | rest census, sweep | unchanged | constant | constant | — | rest-pose seat findings; the head joints in both gaits (≤ 28°) add nothing |
| shells × trunk servos 0.66 / 1.02, shell × battery 0.33, head shells × head servos 0.90 / 1.07, one 0.42 | rest census | 0.64 / 0.73, 0.33, 0.60 / 1.04, **one clears** | same-body: constant | constant | — | rest-only; within decimated-shell uncertainty |
| screws into a body they are not driven into (#58, #59 → shells 0.71 / 0.58; 6 in the hip-yaw/knee/ankle groups in range) | rest census, sweep | unchanged (not posed per frame) | not posed | not posed | — | as before; these are the withdrawn servo-face proposals |

## 5 · The corrected single-joint sweep (`out/fit/sweep.json`, `sweep-depth.json`, rerun 22:06 CST)

Same tool, same 5° step and 0.5° bisection, with onsets keyed by pair **and
side**. 73 range collisions (54 before: 19 "+" onsets had been overwritten by
the "−" pass — 7 at the ankles, 1 at head roll, the rest screws). 4862 s under
a load average of 20–40. The structure onsets that changed:

| joint | side | onset | pair | before the fix |
|---|---|---|---|---|
| left ankle | + | **+0.31°** | ankle bracket × ankle servo | missing (only −0.31 was listed) |
| left ankle | + | +73.4 / +75.3 / +79.7° | ankle servo × foot, shin × ankle bracket, shin × foot | missing |
| right ankle | + | **+0.31°** | ankle bracket × ankle servo | missing |
| right ankle | + | +79.4 / +79.7 / +82.5° | shin × ankle bracket, ankle servo × foot, shin × foot | missing |
| head roll | + | +13.75° | part 29's servo × head-roll servo | missing (−8.1° was listed) |

Every left "+" onset now has its right "−" twin at the same angle (ankle
73.44 / 75.31 / 79.69 / 82.5, knee 70.94 / 75.31 / 79.69 / 89.69, hip yaw
18.12 / 23.75 / 24.69), which is the mirror the model is (§3.1). Depth at the
used-envelope edge (`fit_sweep_depth.py`, Pollen meshes as before):

| joint | used envelope | first structure collision | depth at the edge | verdict |
|---|---|---|---|---|
| left ankle | 0..+45.6° | bracket × servo from **+0.3°** | 2.50 mm at +45.6° | inside the envelope — the same as the right, see §3 |
| right ankle | −32.7..0° | bracket × servo from −0.3° | 2.50 mm at −32.7° | inside the envelope, unchanged |
| left / right knee | ..75.1° / −79.7.. | hip bracket × foot from ±70.9° | 2.10 / 3.73 mm | inside; coupled posing gives 2.99 / 2.81 (§2.2) |
| head roll | ±25° | part 29 × servo from −7.5°, servo × servo from −8.1° and +13.75° | 0.00 mm at ±25° on the crossing-only measure (the closed-mesh check gave 0.76–1.0 mm, REST-CENSUS §part 29) | within the servo-seat family |
| hip yaw, hip roll, hip pitch, neck pitch, head pitch, head yaw | | as in REST-CENSUS | | unchanged |

## 6 · Not done, and the limits of these numbers

- No physical part was measured. The 1.3–1.4 mm horn-seat overlap (§1.3) is a
  model finding; one printed seat's pocket depth would settle it.
- The vendor STEP is the manufacturer's XL330 family model; whether the fitted
  servos are that revision is the identity question
  `research/xl330-mechanical-source-2026-09-08/` leaves open. The six open
  shells were excluded; solid 4 is disjoint from the rest.
- Coupled posing samples the trajectories (every 4th or 8th frame in pass 1,
  every frame in pass 2 for graded pairs); a pair that touches only between
  two pass-1 samples and never reaches 0.05 mm at one is not in the list.
  Fasteners were not posed per frame (the sweep and rest census cover them).
- `yaw_roll_motion` pairs use the review lane's closed repair in memory; the
  simulator STL is still open.
- The parenting audit's holder criterion (0.5 mm over 60°) finds channel-type
  holders only; it cannot see a servo held by two bearings or by screws.
- `placements.json`, every mesh, every drawing and every review package are
  unchanged.

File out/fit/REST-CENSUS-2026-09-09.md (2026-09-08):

# Interference census — 2026-09-09 (rest pose and joint-range sweep)

`tools/prove_fit.py rest` rerun on the current
`ce-assemblies/microduck/current/placements.json` (134 rows: 70 Pollen meshes
seeded from the MJCF + 64 nominal screws), on 2026-09-09 01:30 CST.
Result: `out/fit/rest.json` (this run) and `out/fit/rest.log`.
Previous result preserved unchanged in `out/fit/baseline-2026-09-05/`.

## The previous result was wrong, and it was shipped

The 2026-09-05 `rest.json` (18 AABB candidates, 7 interfering pairs) was the
run the tool's own docstring describes as the metre/millimetre mix-up: every
Pollen mesh shrank 1000x to a speck, so almost nothing could overlap. The
guard that catches this was added to the tool afterwards, but the result file
was never regenerated. That stale file is inside the review snapshots
`research/review-release-2026-09-08/Microduck-Review-C/07 Files for the
engineer/Project files/out/fit/rest.json`, the `parallel-engineering-review`
Review-C snapshot, and the `mesh-repair-2026-09-09/Microduck-Review-F`
manifest. Issued `reviews/vNNNN` packages are immutable; the correction
belongs in the next numbered version, citing this file.

## Measured now

| bucket | pairs | meaning |
|---|---|---|
| screw × the part it is driven into | 93 | thread engagement modelled as overlap; expected. These are the 64 nominal screws whose 52 servo-face proposals are already withdrawn (see `docs/RECREATION-2026-09-08.md`). |
| contact ≤ 0.05 mm | 47 | mating faces and bearing seats touching; expected. |
| 0.05–0.3 mm | 8 | below the mesh decimation floor; reported, not graded. |
| **> 0.3 mm penetration** | **20** (16 distinct pairs) | listed below. |
| screw × a body it is not driven into | 2 | fastener #58 into `left_shell` 0.71 mm, #59 into `right_shell` 0.58 mm. |
| CANNOT DETERMINE | 4 | every pair involving `yaw_roll_motion` (open mesh, 42 boundary edges — the known part-29 defect). |

Assembled bbox 144 × 141 × 264 mm. 399 AABB candidates of 8911 pairs, 287 s.

### Penetrations above 0.3 mm (deduplicated, worst first)

| a | b | depth mm | shared volume mm³ | relief axis / mm |
|---|---|---|---|---|
| upper_leg_left | xl330 (hip-pitch servo) | 4.45 | 99.1 | y 4.95 |
| upper_leg_right | xl330 | 4.45 | 99.1 | y 4.95 |
| yaw2roll | xl330 | 4.33 | 405.6 | x 4.96 |
| bearing_roll/yaw2roll | xl330 | 4.33 | 405.6 | x 4.96 |
| leg (left shin) | xl330 (knee servo) | 4.33 | 379.6 | y 4.71 |
| leg_2 (right shin) | xl330 | 4.33 | 379.6 | y 4.71 |
| motor_support | speaker | 1.70 | 412.5 | z 1.69 |
| top_head_shell | xl330 (head servo) | 1.07 | 24.4 | x 1.24 |
| xl330 (trunk) | left_shell | 1.02 | 10.1 | y 3.04 |
| power_support | np_f970 (battery) | 0.95 | 20.6 | x 0.85 |
| lens | noenoeil (eye) | 0.90 | 359.5 | x 5.94 |
| xl330 (jaw) | bottom_head_shell | 0.90 | 20.2 | z 8.80 |
| yaw_roll_motion bearing | speaker | 0.78 | 6.2 | z 1.00 |
| right_shell | xl330 (trunk) | 0.66 | 4.8 | y 2.17 |
| m12_lens_holder | pcb (Pi Zero 2 W) | 0.44 | 83.6 | x 1.60 |
| np_f970 (battery) | left_shell | 0.33 | 5.8 | z 0.41 |

## Reading, under the tool's own inversion

The real Microduck walks with these meshes, so a collision here is first
evidence that the model is wrong, and only then a design problem.

1. **The six 4.3–4.5 mm servo × host-part hits are one systematic thing, not
   six.** They are identical left/right to the micron, and the relief axis is
   always the servo's horn axis. The Pollen `xl330.stl` visual mesh measures
   29 × 20 × 34 mm; the XL330-M288-T body is 23 mm across the horn axis, so
   the visual mesh carries about 6 mm of horn/idler stack. Where a bracket's
   bearing or horn seat wraps that stack, the overlap volume is the seat itself.
   This is consistent with, and not yet distinguished from, the servo-geometry
   discrepancies already on record in
   `research/xl330-geometry-revision-2026-09-08/` (6 mm modelled pilot vs
   3 mm specified; vendor centre region hollow where the simplified candidate is
   solid). Deciding it needs the vendor STEP servo in place of the visual mesh,
   which that lane owns. Nothing here should change a bracket.
2. **Pocket-seated parts** (speaker in `motor_support`, lens in the eye
   `noenoeil`, lens holder against the Pi Zero board) show large shared
   volumes with sub-2 mm depth: the seat is modelled solid where the real part
   is press-fitted or the pocket is a visual simplification. Lens holder × Pi
   board (0.44 mm, 1.6 mm relief) is the one worth a look in the head, because
   a board cannot be pressed into.
3. **Shell × servo and shell × battery** (0.3–1.1 mm) are within what
   decimated organic shells plus a 23-vs-29 mm servo mesh can produce. They
   are not graded as design collisions; they are graded as unresolved until the
   servo mesh question above is settled.
4. **`yaw_roll_motion` cannot be graded at all** until a closed mesh is used;
   the review lane's repaired 1270-triangle mesh exists but `placements.json`
   still points at the open simulator STL.

Ten of the 38 unique meshes are non-manifold (power_support, np_f970, both
soles and feet, jaw_soft, soft_mouth_top, jaw); one is open (yaw_roll_motion).
Ray-parity volumes on the non-manifold ones are reported but carry that caveat.

## Part 29 (yaw_roll_motion) graded with the closed mesh — added 01:50 CST

`tools/fit_yaw_roll_closed.py` substitutes, in memory only, the review lane's
closed repair `out/review-geometry/microduck-yaw-roll-motion.stl` (same part
frame as the reference: Kabsch on the 1242 shared triangles is identity to
1e-6 mm) and re-measures every AABB-overlapping pair. Result
`out/fit/yaw-roll-closed.json`:

| pair | result |
|---|---|
| yaw_roll_motion × its own xl330 (head-yaw servo) | 404.0 mm³ shared, 0.92 mm depth — the same servo-seat family as yaw2roll (405.6 mm³) and the legs; see reading 1 |
| × both 22×16×4 bearings | 0.02 mm; seated contact |
| × jaw_soft/xl330 | 0.0002 mm³; touching |
| × motor_support, top_head_shell, jaw, bottom_head_shell | clear, zero crossing triangles |
| × fasteners #38–#41 | thread engagement 1.5–2.5 mm; the part they are driven into |

So the opening in part 29 does not put the part into any shell, the jaw or the
motor support at rest. The only overlap it has is the servo-seat overlap every
servo-carrying part has. Range-of-motion is the sweep stage, below.

## Joint-range sweep — added 02:55 CST

`tools/prove_fit.py sweep` is now implemented: each of the 14 hinges is driven
across its full MJCF range in 5° samples with every other joint at zero; only
pairs with exactly one member distal to the joint are re-tested; a pair that is
clear at zero and interferes at a sample is bisected to 0.5° for the angle at
which the collision begins. `tools/fit_sweep_depth.py` then re-poses every
such pair at the edge of the envelope the published policies actually use
(walking + sit/stand joint extremes from `out/motion/legs.json`; head sine
amplitude and slot-crosstalk peaks from `out/motion/head.json`) and measures
penetration depth there. Results: `out/fit/sweep.json`, `out/fit/sweep-depth.json`.

**A defect found and fixed on the way.** The first sweep rotated every part about
the wrong centre: `prove_fit.py` built its zero pose from an all-zero qpos, which
puts the free-joint root at the origin, while `placements.json` is composed with
the trunk at z = 120 mm (the MJCF body pos, i.e. `qpos0`). At rest that cancels;
under rotation every horizontal hinge anchor sat 118–122 mm from its bearing.
`tools/fit_axis_check.py` measures this (`out/fit/axis-check.log`): after the
fix every carrying bearing is 0.02 mm off its joint axis with 0.0° tilt. The
wrong-centre sweep was discarded, not published.

### What the corrected sweep finds

54 clear-at-rest pairs start interfering somewhere in the ranges. Depth at the
used-envelope edge, or at the range end when the collision only begins beyond
the envelope:

| joint | used envelope | first structure collision | depth | verdict |
|---|---|---|---|---|
| hip roll (both) | −8/+11°, −12/+8° | none in ±22° | — | clear |
| hip pitch (both) | −46..0°, 0..32° | none in ±90° | — | clear |
| neck pitch | ±37° | none in −90..60° | — | clear |
| head yaw | ±148° | none in ±170° | — | clear |
| hip yaw (both) | −9/+6°, −4/+13° | shin into battery from ±18.1° | 4.4 mm at ±25° | outside envelope; a single-joint pose the gait never reaches |
| knee (both) | up to 75° / −80° | hip bracket into foot from 70.9° | 2.1 mm (L, 75°), 3.7 mm (R, −80°) | inside the sit/stand extreme, but only with hip pitch and ankle at zero; in the real squat all three move. Needs the sit/stand trajectory posed jointly. |
| head pitch | ±88° (crosstalk peak) | head shells into trunk shells from −66°, power support from −71° | 1.1 / 2.75 mm at −88° | the MuJoCo hull probe in head.json already said self-contact beyond −54°; exact meshes say −66°. Inside the crosstalk envelope, outside the 42° sine amplitude. |
| ankle right | −33..0° | ankle bracket into the shin servo from −0.3° | 2.5 mm at −33° | **asymmetric**: the mirrored motion on the left (0..46°) is clear. Rest census shows both shin servos seated identically, so suspect the right servo mesh's horn side or the ankle_right mesh, not the bracket. |
| ankle left | 0..46° | (−side only) | 2.9 mm at −90° | outside envelope |
| head roll | ±25° | part 29 × roll servo from −7.5° | closed-mesh check: 0.76 mm at −12.5°, 1.0 mm at −25° | within the servo-mesh overwidth (see reading 1); the bearings and shells stay clear |

Screws: 6 nominal screws enter a body they are not driven into inside the
envelope (all in the hip-yaw/knee/ankle groups); these are the withdrawn
servo-face proposals and are not graded.

### Caveats that bound these numbers

- One joint at a time from the zero pose. Coupled poses (squat, walking stance)
  are not swept; the knee finding in particular needs the recorded trajectories
  posed jointly. The MuJoCo hull probe is the only coupled evidence so far.
- Penetration is measured against Pollen's visual meshes including the 29 mm
  servo mesh; a 1 mm depth against a servo is inside that uncertainty.
- `yaw_roll_motion` pairs use the closed repaired mesh only where stated.

## Not done

`access` (driver reach) is documented in the tool and not implemented. The sweep
is single-joint from zero; coupled trajectories are not posed. No physical part was
measured. No placement, mesh or drawing was changed by this census.

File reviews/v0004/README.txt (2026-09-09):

MICRODUCK v0004 - open in your own software / 用你自己的软件打开

Extract, open START HERE.html, or go straight to the folder "00 Open in your own software".
解压后打开 START HERE.html，或直接进入 "00 Open in your own software" 文件夹。

Supplement to review v0003 (zip SHA-256 781bcbb626b81ac0331467e0d77f6511d27626defc1c368079c1ef7b2ec0923f). Same geometry, packed for SolidWorks, Fusion 360, FreeCAD and slicers. Units mm. Not manufacturing approval.

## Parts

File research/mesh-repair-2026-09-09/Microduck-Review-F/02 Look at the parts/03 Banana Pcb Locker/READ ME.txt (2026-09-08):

Banana Pcb Locker
零件 3 / Part 3
Quantity in source list / 清单数量: 1
Origin: our parametric rebuild (latest PASS refcheck ours.stl)
The file is for review. See Questions to resolve before manufacturing. / 仅供评审，生产前请查看待确认事项。
The full historical/reference geometry is in 07 Files for the engineer.

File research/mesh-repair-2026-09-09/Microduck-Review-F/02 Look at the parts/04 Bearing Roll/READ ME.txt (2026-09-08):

Bearing Roll
零件 4 / Part 4
Quantity in source list / 清单数量: 2
Origin: our parametric rebuild (latest PASS refcheck ours.stl)
The file is for review. See Questions to resolve before manufacturing. / 仅供评审，生产前请查看待确认事项。
The full historical/reference geometry is in 07 Files for the engineer.

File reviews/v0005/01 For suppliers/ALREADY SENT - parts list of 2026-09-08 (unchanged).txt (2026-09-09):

Ming 你好！想请你尽快帮我找齐一台 Microduck 的零件，头部最优先。请直接给最快能买到的链接／本地现货店、准确型号、数量、价格和最早到货时间；能在深圳／华强北当天拿到的请优先。先询价和确认，不下单。

【先做头部】
1. Radxa ZERO 3W ×1。原资料写 1GB RAM／32GB eMMC，但官网标准型号表没有这一组合；请确认原机／OEM 型号，或单列现货替代，不能默认等同。
2. IMX219 摄像头板 ×1，M12 镜头 ×1（摄像头已含镜头就不重复），CSI 排线 ×1。板型、视角、排线两端和长度需确认；Radxa 端为 22-pin 0.5mm。
3. 8×8 ToF 模块 ×1，VL53L5CX 或 VL53L8CX，原机代际未确定；请连匹配线束报价。
4. 扬声器 ×1；35×25×7mm、8Ω/2W 仅为候选规格，需要核对实物。麦克风数量／型号待核；公共 HAT BOM 有 LMA2718T421-OA5-2。
5. NFC 读卡器 ×1＋天线 ×2，摄像指示 LED ×1：原机型号未确定，先请帮找原件资料／可用方案。
6. Robot HAT ×1：优先原厂成品／原版本；否则请找能做 PCB＋SMT＋物料代购＋上电测试的厂。公共参考 BOM 有 TLV320AIC3104IRHBR、PAM8406D、BMI088、AP63205、XC6206P182、LM5050-1；不要把这些芯片和整板重复采购。

【整机其余物料】
7. ROBOTIS DYNAMIXEL XL330 共15只（含头部，不能再加算）；M288-T／M077-T 原机子型号待确认。请报原装现货和零售包配件。标准 XL330 额定3.7–6.0V，而资料电池窗口6.6–8.2V，供电方案必须先核对，不能直接替换或接电。
8. 3-pin TTL 舵机总线线束共15–16条，长度逐段确认。零售舵机每只可能含1条180mm线，确认后扣除，不重复买；自压线需 JST EHR-3＋SEH-001T-P0.6。ToF 端 SH 4-pin，喇叭端连接器待确认。
9. 轴承：外径22／内径16／宽4mm ×11；外径15／内径10／宽3mm ×3。第二种请找开式6700/MR6700尺寸候选，别用通常4mm宽的6700ZZ代替；原厂、密封形式和等级均待核。
10. NP-F550 外形2S锂电池2600mAh ×1，匹配充电器 ×1；品牌、保护和接口请确认。
11. imu_to_dxl v2 板 ×1（LSM6DSV16X＋MCU／Dynamixel协议）；banana 电池触点板 ×1。请一起问原板供应或打样／贴片渠道。
12. M2螺钉、螺母、热熔铜螺母及少量M2.5螺钉：长度／牙型还没实物核实，请先找齐规格现货渠道。旧采购估算漏了模型里的M2×5、M2×10、M2.5×8；舵机附送TAP自攻螺钉不能按普通公制螺钉抵扣。
13. 蓝牙手柄 ×1、USB-C线 ×1。打印件我们这边做，需硬件用PLA及软嘴／脚底用TPU；TPU硬度和用量待验证。

请先回复头部关键件最早到货方案、缺货项和PCB工程师联系方式。型号不确定的请发照片／尺寸／数据表，我们确认后再买。现有 PCB 包仍有 DRC／版本／连接器问题，只供工程评审询价，未放行生产。谢谢！

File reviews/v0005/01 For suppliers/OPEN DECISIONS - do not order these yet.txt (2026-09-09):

OPEN DECISIONS (Leif's side) - do not order these until settled / 未决事项（Leif 方）：未定前不要下单

- Servo route: Dynamixel XL330 vs Feetech STS3215 / 舵机路线：XL330 还是 飞特 STS3215
    Quote both (Packet B). Do not buy servos. Also the XL330 supply voltage conflict is real, not a typo.
    两边报价（Packet B），先不买舵机。XL330 供电电压冲突是真实存在的。
- Screw thread form and lengths / 螺丝牙型和长度
    Quote only; the servo screws are M2 tapping into Ø1.6 pilots, max 3 mm deep, not standard M2.
    仅报价；舵机螺钉为 Ø1.6 底孔自攻，最深 3mm，不是普通 M2。
- Radxa ZERO 3W configuration / Radxa ZERO 3W 配置
    The 1 GB/32 GB SKU does not exist; propose what is in stock, 2 GB/16 GB preferred.
    1GB/32GB 不存在；报现货配置，优先 2GB/16GB。
- Camera board, lens FOV, CSI cable / 摄像头板、镜头视角、排线
    Board revision and FOV not fixed; quote options, buy after photo/datasheet.
    板型和视角未定；报几种，看照片/规格书后再买。
- ToF generation (L5CX vs L8CX) / ToF 代际
    Quote both carriers with mounting drawings.
    两种模块都报价并附安装图。
- PCBs / PCB
    DRC failures open; quote from Gerbers, do not fabricate.
    DRC 未通过；按 Gerber 报价，不投产。
- Charger float voltage (8.2/8.4/8.7/8.8 V) / 充电器浮充电压
    Affects the MCP73213 suffix; nobody has chosen yet.
    影响 MCP73213 后缀；尚未选定。

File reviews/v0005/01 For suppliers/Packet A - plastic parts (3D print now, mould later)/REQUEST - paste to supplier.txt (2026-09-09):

REQUEST FOR QUOTE - printed plastic parts / 询价：3D 打印塑料件

EN: Please quote FDM printing of the attached 30 parts (36 pieces per robot, 32 PLA + 4 TPU 85A pieces, about 122 g PLA/TPU per set) at 1 / 10 / 100 sets, 0.2 mm layer, natural or grey colour, supports removed, bearing bores to size. Files: STL zip (every part), STEP zip (same parts as STEP), 3MF plates, PDF drawings for 22 parts. Also state: (a) your printer type, (b) delivery time per set, (c) whether you can do 1 mm walls (rigidity plate) and Ø15 bearing seats within +0/-0.1 mm. Separate question for later: injection-mould tooling estimate for the 10 visible parts marked "mould candidate" in PRINTED PARTS.xlsx at 1000 sets, after we redesign for draft.

中文：请按附件报 30 个零件（每台 36 件，PLA 32 件 + TPU 85A 4 件，每套约 122 克）的 FDM 打印价格，数量 1 / 10 / 100 套，层高 0.2mm，本色或灰色，去除支撑，轴承孔按图到位。文件：STL 压缩包（全部零件）、STEP 压缩包（同样零件）、3MF 打印盘、22 个零件的 PDF 图纸。另请说明：(a) 打印机类型，(b) 每套交期，(c) 能否做 1mm 薄壁（加强板）和 Ø15 轴承位公差 +0/-0.1mm。另一个以后的问题：PRINTED PARTS.xlsx 中标注 "mould candidate" 的 10 个外观件，我们改好拔模后，1000 套的注塑开模估价。

Delivery / 收货：广东省深圳市福田区华强北 深南中路2070号 电子科技大厦 405室  收件人：Leif Rydenfalk  电话：[Leif 填写]

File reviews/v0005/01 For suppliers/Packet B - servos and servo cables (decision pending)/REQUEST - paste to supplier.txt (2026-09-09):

SERVOS - TWO ROUTES, QUOTE BOTH, BUY NOTHING YET / 舵机：两条路线都报价，先不买

Why: the current CAD is modelled on the ROBOTIS XL330-M288-T (imported, about US$23.90 each, 15 per robot). Feetech STS3215 7.4 V (Shenzhen, about ¥100) would cut cost ~60% and remove the import, but the leg and head brackets must be re-modelled for it. Leif decides after seeing both prices. Also note: the XL330 is rated 3.7-6 V while our battery window is 6.6-8.2 V, so the power route is not settled either.
原因：现有 CAD 按 ROBOTIS XL330-M288-T 建模（进口，约 23.9 美元/只，每台 15 只）。飞特 STS3215 7.4V（深圳，约 100 元）可省约 60% 并免进口，但腿部和头部支架要重新建模。Leif 看到两边价格后决定。另外 XL330 额定 3.7-6V，而电池窗口 6.6-8.2V，供电方案也未定。

Quantities / 数量：1 robot: 15 + 2 spare = 17；10 robots: 152；100 robots: 1502.

=== Route 1: Feetech STS3215 (paste to 1688 / 淘宝 / 飞特官方店) ===
你好，我在深圳华强北做一个双足机器人项目，需要采购舵机：

型号：STS3215  7.4V  19kg.cm  串行总线舵机
数量：16 个（14 个装机 + 2 个备用）
需要：舵机 + 配套连接线 + 舵机支架/舵盘（如有套装请推荐）

请问：
1. 单价和 16 个的总价是多少？可以开发票吗？
2. 现货吗？深圳市内可以自提或当天送达吗？
3. 有没有配套的总线控制板（例如 Waveshare Bus Servo Adapter）一起报价？
4. 提供 STEP 或 DXF 的外形尺寸图吗？我需要按尺寸建模安装位。

收货地址：深圳市福田区华强北深南中路2070号 电子科技大厦 405室
谢谢！

=== Route 2: ROBOTIS DYNAMIXEL XL330-M288-T ===
EN: Please quote genuine ROBOTIS DYNAMIXEL XL330-M288-T (SKU 902-0163-000) at 17 / 152 / 1502 pieces, with Robot Cable-X3P 180 mm leads (10-pack, SKU 903-0251-000) for 16 / 160 / 1600 leads, and state whether each retail servo includes one lead. Confirm M288-T vs M077-T availability. Lead time and whether stock is in Shenzhen or imported.
中文：请报原装 ROBOTIS DYNAMIXEL XL330-M288-T（货号 902-0163-000）17 / 152 / 1502 只的价格，以及 X3P 180mm 舵机线（10 条装，903-0251-000）16 / 160 / 1600 条；请说明零售舵机是否每只附一条线，M288-T 与 M077-T 哪个有货，交期，深圳现货还是进口。

Harness alternative (if we crimp our own) / 自制线束替代：JST EH 3-pin housings EHR-3 x32 per robot, SEH-001T-P0.6 contacts x96 per robot, 22 AWG wire.

Delivery / 收货：广东省深圳市福田区华强北 深南中路2070号 电子科技大厦 405室  收件人：Leif Rydenfalk  电话：[Leif 填写]

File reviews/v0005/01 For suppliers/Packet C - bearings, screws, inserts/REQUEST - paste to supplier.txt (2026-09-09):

BEARINGS, SCREWS, INSERTS / 轴承、螺丝、热熔螺母

Per robot / 每台：bearing 22x16x4 (MR1622, quote ZZ shielded AND open) x11；bearing 15x10x3 (MR6700 open, 3 mm wide - NOT the 4 mm 6700ZZ) x3；M2 socket-head screws (4/6/8/12 mm, about 195 total) + M2 nuts x50 + M2.5x6 x20；M2 heat-set brass inserts ~3 mm x60.
For 10 robots multiply by 10; for 100 by 100. Bearings can be bought now for 1 robot. Screws: QUOTE ONLY, or buy one cheap assortment; thread form and lengths are not final (the servo tapping screws are a separate question).
10 台乘 10，100 台乘 100。轴承可先买 1 台用量。螺丝：仅报价，或买一套便宜套装；牙型和长度未定（舵机自攻螺钉另行确认）。

华强北 walk-in / 一句话：
你好，我要买微型轴承 MR1622-ZZ 十一个、MR6700 三个，
还有 M2 内六角螺丝（4/6/8/12mm）、M2 热熔螺母 60 个。有现货吗？

Taobao references found by the replica builder (not verified by us) / 复刻者用过的淘宝链接（未经我们核实）：NBZH 永天轴承 ¥2.2 (539024647147)；鑫燚 NSK both sizes ¥5 (670727787832)；广州信邦 M2 套装 600 pcs ¥26.8 (842110292995)；榕誉 M2 热熔螺母 400 pcs ¥22 (1000673642588).

Delivery / 收货：广东省深圳市福田区华强北 深南中路2070号 电子科技大厦 405室  收件人：Leif Rydenfalk  电话：[Leif 填写]

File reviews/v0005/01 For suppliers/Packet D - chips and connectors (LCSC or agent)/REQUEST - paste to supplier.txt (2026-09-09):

CHIPS AND CONNECTORS / 芯片与连接器

EN: Quote the lines in LINES.csv at 1 / 10 / 100 robots (quantity per robot in the sheet), authorised channel with date codes. Key parts: TLV320AIC3104IRHBR (LCSC C181753, verified), LSM6DSV16XTR, BMI088 (optional), NFC route PN7150 or ST25R3916 (open), JST SH 4-pin SHR-04V-S-B and GH 2-pin GHR-02V-S housings with contacts (2 each per robot). Buy only together with the PCB build.
中文：请按 LINES.csv 报 1 / 10 / 100 台的价格（每台用量见表），正规渠道并注明批号。主要器件：TLV320AIC3104IRHBR（立创 C181753，已核实）、LSM6DSV16XTR、BMI088（可选）、NFC 方案 PN7150 或 ST25R3916（未定）、JST SH 4pin SHR-04V-S-B 与 GH 2pin GHR-02V-S 壳体及端子（每台各 2 个）。与 PCB 一起采购。
LCSC upload file: "LCSC upload - lcsc-bom.csv" / 立创 BOM 工具可直接上传。

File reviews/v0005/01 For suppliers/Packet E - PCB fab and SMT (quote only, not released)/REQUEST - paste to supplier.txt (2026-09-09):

PCB FAB AND SMT - QUOTE ONLY, DESIGN NOT RELEASED / PCB 打样与贴片：仅报价，设计未放行

IMPORTANT: all three boards still have open design-rule failures and connector/version questions. Please quote from the Gerbers but DO NOT manufacture until Leif releases them. / 重要：三块板都还有 DRC 未通过和连接器/版本问题。请按 Gerber 报价，Leif 放行前不要投产。

Boards / 板：
  P1: Robot HAT 65.0 x 30.0 mm, 2 layers, 0.15 mm min track
  P2: imu_to_dxl v2 40.0 x 22.0 mm, 2 layers, 0.15 mm min track
  P3: banana battery-contact strip 45.8 x 4.6 mm, corner R0.5, ENIG

EN: Quote bare boards at 5 / 50 / 500 pieces each (2-layer, 1.6 mm FR-4, HASL lead-free; P3 ENIG), and turnkey SMT for P1 and P2 with the BOM and positions.csv inside each fab zip. State minimum track/space you accept (we have 0.15 mm), lead time, and whether you can source the ICs listed in Packet D. We also need a contact for a PCB engineer who can review the HAT design.
中文：请报裸板 5 / 50 / 500 片价格（两层，1.6mm FR-4，无铅喷锡；P3 沉金），以及 P1、P2 的贴片代工价（BOM 和坐标文件在各自 fab 压缩包内）。请说明可接受的最小线宽/线距（我们是 0.15mm）、交期，以及能否代购 Packet D 的芯片。另外我们需要一位能评审 HAT 板设计的 PCB 工程师联系方式。
Fab packages included / 附件：3 of 3

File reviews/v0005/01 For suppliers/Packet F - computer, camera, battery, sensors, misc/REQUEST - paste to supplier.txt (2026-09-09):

HEAD PARTS FIRST / 头部件优先（Radxa、摄像头、ToF、喇叭、电池）

This is the same list Leif sent on 2026-09-08 (see ALREADY SENT). Nothing changed. For each item we need: link or local shop, exact model, price, earliest delivery, and a photo/datasheet if the model is uncertain. Confirm before buying.
与 2026-09-08 已发清单一致（见 ALREADY SENT），没有变化。每项需要：链接或本地店、准确型号、价格、最早到货，型号不确定的发照片/规格书。确认后再买。

B3  Radxa ZERO 3W single-board computer
   EN: CONFIRM FIRST: the 1 GB/32 GB configuration is not in Radxa's catalogue. Propose what is in stock (2 GB/16 GB preferred).
   中文: 先确认：1GB/32GB 配置官网目录没有。请报现货配置（优先 2GB/16GB）。
   Spec: Radxa ZERO 3W, RK3566 quad Cortex-A55, 40-pin GPIO header PRE-SOLDERED, 22-pin MIPI CSI 0.5 mm, Wi-Fi 6 / BT 5.4, 2x USB-C. Configuration required: 1 GB LPDDR4 with 32 GB eMMC if Radxa will build it (no such catalogue SKU); otherwise quote RS107-D1E8H1W15 (1 GB / 8 GB, header) and RS107-D4E32H1W15 (

B4  NP-F550-class battery plus one dual charger per robot (whole retail kit)
   EN: Confirm pack and charger identity, then buy 1 set.
   中文: 确认电池和充电器型号后可买 1 套。
   Spec: Identify original pack and dual charger. Conditional target NP-F550-class 2S 2600 mAh pack, reference 70 × 38 × 20 mm class; provide contact/latch drawing, continuous/pulse-current ratings and temperature limits, cell manufacturer, protection trip/recovery thresholds. Runtime 6.6/8.2 V indication is

B6  IMX219 camera board, M12 mount, with lens
   EN: Confirm board revision and lens; send photo/datasheet before buying.
   中文: 先确认板型和镜头，购买前发照片/规格书。
   Spec: Conditional candidate only: Sony IMX219 module with nominal24x25mm-class board and M12 optics. Provide exact board revision, complete mechanical drawing/barrel dimensions, lens EFL/FOV at active crop, connector pinout/pitch/contact side and included FFC. Pollen has not fixed public camera FOV. Rejec

B7  M12 wide-angle lens (only if the camera board is bought bare)
   EN: Quote 70/90/140 degree options; FOV not fixed.
   中文: 报 70/90/140 度三种；视角未定。
   Spec: M12 (S-mount) lens for a 1/4-inch IMX219 sensor. TARGET FOV IS NOT FIXED - Pollen's press kit says the camera FOV is 'still being finalised' and the only community figure is ~62 deg HFOV, unverified. Quote 70 deg, 90 deg and 140 deg options and state the FOV ON A 1/4-INCH SENSOR, not on the sensor t

B8  22-pin 0.5 mm MIPI CSI FFC ribbon, Radxa to camera
   EN: Buy 100/150/200 mm one each once camera end is known.
   中文: 摄像头端确定后各买一条 100/150/200mm。
   Spec: Quote CSI FFC only after exact camera and host connector identities are frozen: pin map, pitch, contact sides, stiffeners, insertion depths and routed length with bend/slack allowances. Host22pin0.5mm; camera end remains unresolved. No15mm manufacturing cut length is specified.

B9  ToF module on four-pin J5/Qwiic interface; original carrier unknown
   EN: Quote VL53L5CX and VL53L8CX carriers with mounting drawing.
   中文: VL53L5CX 与 VL53L8CX 模块都报价，附安装尺寸图。
   Spec: Identify original carrier revision and optical/mounting geometry first. Existing interface is four-pin J5 GND/3V3/SDA/SCL with 7-bit 0x29. L5 can use 3.3 V directly; L8 requires its own compliant lower-voltage power/logic design. Request exact connector, board height, hole positions, window/crosstal

B12  Speaker, reference envelope 35 x 25 x 7 mm (head); original electrical specification unknown
   EN: Buy one cheap candidate, measure, then confirm.
   中文: 先买一个便宜候选，量尺寸后确认。
   Spec: Identify the original speaker first. Reference placeholder is 35.0 x 25.0 x 7.0 mm, not a measured cavity tolerance. Conditional sourcing target 8 ohm nominal, 2 W; these electrical values are representative assumptions. Request dimensioned drawing including connector/tabs, impedance, SPL test condi

B13  Microphone(s)
   EN: Not quotable yet (type and count unknown).
   中文: 暂无法报价（类型、数量未定）。
   Spec: NOT QUOTABLE. Type (electret vs MEMS), count, package, sensitivity, position and connector are all unknown; there is no mesh for it in the MJCF, so even the cable length is unmeasurable (wiring/CABLES.md row 19 = CANNOT DETERMINE). No RFQ can be written until a production unit is opened.

B15  Camera-in-use indicator LED
   EN: Not quotable yet.
   中文: 暂无法报价。
   Spec: NOT QUOTABLE - colour, package, brightness, GPIO and whether it is on the HAT or a flying lead are all unknown.

B16  Bluetooth gamepad (Xbox-style)
   EN: Commodity; any Xbox-layout BT gamepad.
   中文: 通用件；任意 Xbox 布局蓝牙手柄。
   Spec: Bluetooth HID gamepad, Xbox-compatible mapping, pairing to the Radxa's BT 5.4 radio. Model unspecified by Pollen.

B17  USB-C cable
   EN: Commodity.
   中文: 通用件。
   Spec: USB-C to USB-C or USB-A, length and current rating unspecified. Commodity.

Delivery / 收货：广东省深圳市福田区华强北 深南中路2070号 电子科技大厦 405室  收件人：Leif Rydenfalk  电话：[Leif 填写]

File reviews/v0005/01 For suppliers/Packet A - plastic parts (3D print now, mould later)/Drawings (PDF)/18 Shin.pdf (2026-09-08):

7.9500
20.0000
58.0000
Ø6.0000
7.2500
10.0000
48.0000
Ø5.5000
3.4900
10.0000
6.0000
Ø4.8400
3.0000
2.0000
28.5000
Ø4.8400
3.0000
18.0000
28.5000

Ø4.4000
4.4900
5.7570
43.7570
Ø4.4000
4.4900
5.7570
52.2430
Ø4.4000
4.4900
14.2430
43.7570
Ø4.4000
4.4900
14.2430
52.2430
Ø2.7000
4.3000
10.0000

6.0000
Ø2.4000
2.3000
2.0000
28.5000
Ø2.4000
2.3000
18.0000
28.5000
Ø2.2000
2.7600
5.7570
43.7570
Ø2.2000
2.7600
5.7570
52.2430
Ø2.2000
2.7600

14.2430
43.7570
Ø2.2000
2.7600
14.2430
52.2430
Ø8.0000
Ø4.9200
0.5000
Ø15.9000
1.9500
Ø10.0000
3.2000
Ø10.0000
0.5000
Ø4.9200
2.2900
R1.1000
R1.2000

R1.3500
R2.2000
R2.4200
R2.4600
R2.7500
R3.0000
R4.0000
R5.0000
R7.9500
0.0280
2.4000
14.0000
2.4500

2.0000

28.2230
1.0000
5.5000
2.4500

6.0000

32.4730
5.0000
11.5000
5.3000

10.0000

32.9730
1.0000
5.5000
2.4500

14.0000

32.4730
2.4000
14.0000
2.4500

18.0000

28.2230

E001 R7.9500

E002 R7.9500

E003 R1.1000

E004 R1.1000

E005 R1.1000

E006 R3.0000

E007 R1.1000

E008 R2.4200

E010 R1.2000

E011 R1.2000

E012 R1.2000

E013 R1.2000

E014 R1.2000

E015 R1.2000

E016 R2.4200

E017 R2.4200

E018 R2.2000

E019 R2.2000

E020 R2.2000

E021 R2.2000

E022 R2.2000

E023 R2.2000

E024 R2.4200

E025 R2.4200

E026 R2.2000

E027 R2.2000
E028 R2.2000

E029 R2.2000

E030 R2.2000

E031 R2.2000

E032 R2.2000

E033 R2.2000

E034 R2.2000

E035 R2.2000

E036 R2.4200

E037 R2.4200

E038 R3.0000

E039 R2.4200

E040 R2.4200

E041 R5.0000

E042 R1.1000

E043 R1.1000

E044 R1.1000

E045 R1.1000

E046 R5.0000

E048 R2.4200

E049 R1.2000

E050 R1.2000

E051 R1.2000

E052 R1.2000

E053 R1.2000

E054 R1.2000

E055 R5.0000

E056 R5.0000

E057 R2.7500
E058 R4.0000

E059 R2.7500

E060 R4.0000

E062 R2.4600

E063 R1.3500

E064 R2.4600

## ISOMETRIC 1 FRONT LEFT

RENDER 1 / SCALE 5.89745:1

MICRODUCK-SHIN — NOMINAL mm outline envelope length
outline envelope width
outline envelope height
hole 1 diameter (along x)
hole 1 depth
hole 1 position from the Y datum face hole 1 position from the Z datum face counterbore 2 diameter (along x) counterbore 2 depth
counterbore 2 position from the Y datum face counterbore 2 position from the Z datum face counterbore 3 diameter (along x) counterbore 3 depth
counterbore 3 position from the Y datum face counterbore 3 position from the Z datum face counterbore 4 diameter (along x) counterbore 4 depth
counterbore 4 position from the Y datum face counterbore 4 position from the Z datum face

CANNOT DETERMINE — chamfer: A4 requires size and angle on every chamfer; cecad.inspect has no chamfer classifier — a chamfer is a planar face bridging two faces at an angle and nothing here identifies one SETTLED BY: a chamfer classifier in cecad.inspect (planar face whose two neighbours meet it at equal angles), or the builder declaring its chamfers in the part record

## ISOMETRIC 2 FRONT RIGHT

RENDER 2 / SCALE 5.89745:1

MEASURED FEATURES — mm
counterbore 5 diameter (along x) counterbore 5 depth
counterbore 5 position from the Y datum face counterbore 5 position from the Z datum face counterbore 6 diameter (along x) counterbore 6 depth
counterbore 6 position from the Y datum face counterbore 6 position from the Z datum face counterbore 7 diameter (along x) counterbore 7 depth
counterbore 7 position from the Y datum face counterbore 7 position from the Z datum face counterbore 8 diameter (along x) counterbore 8 depth
counterbore 8 position from the Y datum face counterbore 8 position from the Z datum face hole 9 diameter (along x)
hole 9 depth
hole 9 position from the Y datum face

CANNOT DETERMINE — rib: A4 requires thickness, height and pitch on every rib; nothing here groups faces into a rib SETTLED BY: a rib classifier (parallel thin prisms standing off a wall), or the builder declaring its rib pitch

## ISOMETRIC 3 REAR RIGHT

RENDER 3 / SCALE 5.89745:1

MEASURED FEATURES — mm
hole 9 position from the Z datum face hole 10 diameter (along x)
hole 10 depth
hole 10 position from the Y datum face hole 10 position from the Z datum face hole 11 diameter (along x)
hole 11 depth
hole 11 position from the Y datum face hole 11 position from the Z datum face hole 12 diameter (along x)
hole 12 depth
hole 12 position from the Y datum face hole 12 position from the Z datum face hole 13 diameter (along x)
hole 13 depth
hole 13 position from the Y datum face hole 13 position from the Z datum face hole 14 diameter (along x)
hole 14 depth

CANNOT DETERMINE — draft: A4 requires every draft angle; no face here is tested for draft against a pull direction SETTLED BY: a pull direction on the part record, then the angle of every planar face to it

## ISOMETRIC 4 REAR LEFT

RENDER 4 / SCALE 5.89745:1

MEASURED FEATURES — mm
hole 14 position from the Y datum face hole 14 position from the Z datum face hole 15 diameter (along x)
hole 15 depth
hole 15 position from the Y datum face hole 15 position from the Z datum face groove 1 outer Ø
groove 1 core Ø
groove 1 depth
boss / outside diameter 1
boss 1 length along its axis boss / outside diameter 2
boss 2 length along its axis boss / outside diameter 3
boss 3 length along its axis
boss / outside diameter 4
boss 4 length along its axis
radius R1.10 (8 edges, 8 full circles) radius R1.20 (6 edges, 2 full circles)

CANNOT DETERMINE — step: A4 requires every step and shoulder; nothing here classifies a shoulder between two coaxial diameters or two parallel faces SETTLED BY: a step classifier, or the section views declaring their stations

## TOP-DOWN RENDER

RENDER 5 / SCALE 5.89745:1

MEASURED FEATURES — mm
radius R1.35 (2 edges, 2 full circles) radius R2.20 (12 edges, 4 full circles) radius R2.42 (6 edges, 0 full circles) radius R2.46 (2 edges, 2 full circles) radius R2.75 (2 edges, 2 full circles) radius R3.00 (2 edges, 2 full circles) radius R4.00 (2 edges, 2 full circles) radius R5.00 (4 edges, 4 full circles)
radius R7.95 (2 edges, 2 full circles)
thinnest wall
slot mouth on a plane normal to x, 8 edge(s) — width
slot mouth on a plane normal to x, 8 edge(s) — length
slot mouth on a plane normal to x, 8 edge(s) — depth
slot mouth on a plane normal to x, 8 edge(s) — position from the y datum
slot mouth on a plane normal to x, 8 edge(s) — position from the z datum
pocket mouth on a plane normal to x, 4 edge(s) — width pocket mouth on a plane normal to x, 4 edge(s) — length pocket mouth on a plane normal to x, 4 edge(s) — depth pocket mouth on a plane normal to x, 4 edge(s) — position from the y datum

CANNOT DETERMINE — mate: A4 requires every surface that mates with another part, with the mating part named by its triad ref; the mates live in ce-assemblies/*/joints.json and are not read here SETTLED BY: reading this part's joints out of the assemblies that use it and matching each mate to a face

## BOTTOM-UP RENDER

RENDER 6 / SCALE 5.89745:1

MEASURED FEATURES — mm
pocket mouth on a plane normal to x, 4 edge(s) — position from the z datum
pocket mouth on a plane normal to x, 36 edge(s) — width
pocket mouth on a plane normal to x, 36 edge(s) — length pocket mouth on a plane normal to x, 36 edge(s) — depth
pocket mouth on a plane normal to x, 36 edge(s) — position from the y datum
pocket mouth on a plane normal to x, 36 edge(s) — position from the z datum
pocket mouth on a plane normal to x, 4 edge(s) — width
pocket mouth on a plane normal to x, 4 edge(s) — length
pocket mouth on a plane normal to x, 4 edge(s) — depth
pocket mouth on a plane normal to x, 4 edge(s) — position from the y datum
pocket mouth on a plane normal to x, 4 edge(s) — position from the z datum
slot mouth on a plane normal to x, 8 edge(s) — width
slot mouth on a plane normal to x, 8 edge(s) — length
slot mouth on a plane normal to x, 8 edge(s) — depth
slot mouth on a plane normal to x, 8 edge(s) — position from the y datum
slot mouth on a plane normal to x, 8 edge(s) — position from the z datum

CANNOT DETERMINE — wall: A4 wants a wall thickness at every distinct station; only the thinnest wall is measurable off the solid without a station list SETTLED BY: the drawer declaring the section stations it dimensions, or a section per shell region

A

B

C

20.00

58.00

4x Ø2.20 THRU
C'BORE Ø4.40x4.49 +X

2x Ø2.40 THRU
C'BORE Ø4.84x3.00 +X

Ø6.00 THRU

Ø2.70 THRU
C'BORE Ø5.50x3.49 -X

R7.95

R5.00

R4.00

R3.00

R2.75

R2.46

R2.42

R2.20

R1.35

R1.20

R1.10

## RIGHT VIEW

-Y > Z ^

7.95

58.00

## FRONT VIEW

-X > Z ^

7.95

55.28

1.38 WALL

2.30 WALL

## SECTION A-A

## DETAIL A

SCALE 4:1

R5.00

R4.00

R2.75 R2.46

R1.35

## DETAIL B

SCALE 4:1

R7.95

R2.42

R1.20

## DETAIL C

SCALE 4:1

R7.95

R3.00

R2.20

R1.10

A

A

### HOLE TABLE — 8 POSITIONS

A1 | Ø2.20 THRU | 26.24 | 40.02 | Ø4.40x4.49 +X
A2 | Ø2.20 THRU | 17.76 | 40.02 | Ø4.40x4.49 +X
A3 | Ø6.00 THRU | 22.00 | 35.78 | -
A4 | Ø2.20 THRU | 26.24 | 31.53 | Ø4.40x4.49 +X
A5 | Ø2.20 THRU | 17.76 | 31.53 | Ø4.40x4.49 +X
A6 | Ø2.40 THRU | 30.00 | 16.28 | Ø4.84x3.00 +X
A7 | Ø2.40 THRU | 14.00 | 16.28 | Ø4.84x3.00 +X
A8 | Ø2.70 THRU | 22.00 | -6.22 | Ø5.50x3.49 -X

# MICRODUCK SHIN

2:1
A0 / THIRD ANGLE / mm
7.95 x 20.00 x 58.00
3.39 cm3
CAD SOURCE: part:microduck-shin
DATUM: XYZ MINIMUM ENCLOSING PLANES
XYZ origin mm: 32.5000, 12.0000, -12.2230
GENERAL TOLERANCE CANNOT DETERMINE — SEE PRINT / DFM NOTES UNLESS STATED. DRAFT — NOT RELEASED

PRINT / DFM

ORIENTATION: upright, Z-up (8 x 20 x 58 mm)
THINNEST WALL, WHOLE SOLID (RAY MINIMUM): 0.0280 mm — a distance through material, NOT a printable wall where it falls on an edge, a fillet run-out or a chamfer tip. Printability is judged on the next line.
PRINTABLE MINIMUM WALL: 1.0000 mm (smallest median wall over a 3.1340 mm neighbourhood, cecad.inspect.printable_wall_detail) against a 0.8000 mm floor (2 perimeters @ 0.4 mm nozzle): VERDICT PASS

PRINT / DFM

15 horizontal bore(s) bridge at the crown: ream any bearing or press-fit bore to size
FILAMENT: PLA, ~4 g (modelled), 290 layers @ 0.2 mm

SOURCE / PROCESS
RECREATION MATERIAL: PLA
PROCESS: FDM
RECORD: ce-parts/microduck-shin/component.json
GEOMETRY SOURCE: reference/pollen-microduck-rl/assets/leg.stl (Onshape doc 804927696f06d877f3f1803e, exported by onshape-to-robot)
ORIGINAL MATERIAL / SURFACE FINISH: CANNOT DETERMINE; obtain original specification or measure original part.
FASTENER LENGTH / TORQUE / FIT CLASS: CANNOT DETERMINE; verify interface stack and test production coupon.
KNEE MATE CONTRACT: connection:spline-xl330-horn
MATING PART: part:xl330-m288-t
ANKLE MATE CONTRACT: connection:press-fit-bearing-15x10x3 MATING PART: part:bearing-15x10x3

HIDDEN ARC LOCATORS / DATUM XYZ mm E009 R2.4200 / SWEEP 55.7354 deg CENTRE 3.7000, 2.0000, 28.5000 AXIS 1.0000, 0.0000, 0.0000 START 3.7000, 2.0000, 30.9200 END 3.7000, -0.0000, 29.8625

E047 R2.4200 / SWEEP 55.7354 deg CENTRE 3.7000, 18.0000, 28.5000 AXIS 1.0000, 0.0000, 0.0000 START 3.7000, 20.0000, 29.8625 END 3.7000, 18.0000, 30.9200

E061 R1.3500 / SWEEP 360.0000 deg CENTRE 3.4900, 10.0000, 6.0000 AXIS 1.0000, 0.0000, 0.0000 START 3.4900, 10.0000, 7.3500 END 3.4900, 10.0000, 7.3500

DRAFTING GAPS — NOT RELEASED
E009 / E047 / E061 have measured coordinate locators; section or detail leaders remain required by A.5.
Enlarged shaded feature-cluster details and non-circular feature locator audit remain incomplete.

FRAME OCCUPANCY 99.88%

TAG | SIZE | Y | Z | C'BORE

every row measured off the solid; positions are model coordinates, mm. C'BORE side is the face it opens on; INT = centred in the bore, opening on neither face.

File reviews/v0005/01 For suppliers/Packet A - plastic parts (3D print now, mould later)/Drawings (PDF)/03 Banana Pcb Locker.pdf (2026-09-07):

54.0153
3.8000
6.6260
Ø2.1740
1.5000
2.0076
4.6130
Ø2.1740
1.5000
52.0076
4.6130
R1.0900
0.9210
1.9660
2.4660
2.3000
10.1076
1.0130
1.9660
2.4660
2.3000
43.9076
1.0130

54.02

6.63

2.01
4.61

52.01

4.61

2x Ø2.17 THRU

R1.09

50.00

## FRONT VIEW

-X ? Z ?

54.02

3.80

## TOP VIEW

X ? Y ?

1.50

4.77

0.93 WALL

1.50 WALL

## SECTION A-A

## ISOMETRIC VIEW

54.02 x 3.80 x 6.63 mm

R1.09

## DETAIL A

SCALE 10:1

A

A

A

ISOMETRIC 1 ? FRONT-LEFT ? 1000 x 324 px, RENDERED OFF THIS SOLID | ISOMETRIC 2 ? FRONT-RIGHT ? 1000 x 513 px, RENDERED OFF THIS SOLID | ISOMETRIC 3 ? REAR-RIGHT ? 1000 x 513 px, RENDERED OFF THIS SOLID
ISOMETRIC 4 ? REAR-LEFT ? 1000 x 394 px, RENDERED OFF THIS SOLID | TOP-DOWN RENDER ? 1000 x 394 px, RENDERED OFF THIS SOLID | BOTTOM-UP RENDER ? 1000 x 394 px, RENDERED OFF THIS SOLID

NOTES

1. ALL DIMENSIONS IN mm AND DEGREES. EVERY DIMENSION AND EVERY HOLE CALLOUT WAS MEASURED OFF THE SOLID.
2. PROCESS: FDM.
3. THINNEST WALL, WHOLE SOLID (RAY MINIMUM): 0.9210 mm, AT X=25.809
Y=35.500 Z=52.874 ? MEASURED OVER THE WHOLE SOLID BY RAY+EXACT AT 0.3700 mm SAMPLE SPACING (A FEATURE NARROWER THAN THAT CAN BE MISSED). THIS IS A DISTANCE THROUGH MATERIAL, NOT A WALL: AT AN EDGE, A FILLET RUN-OUT OR A CHAMFER TIP IT IS REAL AND UNPRINTABLE BY DEFINITION. DO NOT JUDGE PRINTABILITY BY IT ? THE NEXT NOTE IS THE ONE THAT DOES.
4. PRINTABLE MINIMUM WALL: 0.9236 mm, AT X=25.925 Y=35.375 Z=54.170 ? MEASURED AS THE SMALLEST MEDIAN WALL OVER A NEIGHBOURHOOD OF 1.1100 mm (>= 8 SAMPLES), RAYS CAPPED AT 4.000 mm, BY cecad.inspect.printable_wall_detail. AGAINST THE 0.8000 mm FLOOR (2 PERIMETERS @ 0.4 mm NOZZLE, cecad/printed.py:801): VERDICT PASS
5. GENERAL TOLERANCE CANNOT DETERMINE ? SEE PRINT / DFM NOTES UNLESS STATED.
6. SECTION A-A AT X=-25.00: THINNEST MATERIAL IN THIS PLANE ONLY 0.93 mm, AT Y=36.49, Z=55.15 ? A SCAN OF ONE CUT, NOT THE PART MINIMUM.
7. FRONT VIEW: hidden lines SUPPRESSED: all 768 edge samples still land on drawn ink without them.
8. TOP VIEW: hidden lines KEPT: without them 48 of 764 edge samples have no ink within 0.35 mm (worst 0.563 mm) and the feature would be missing from the sheet.
PRINT / DFM
1. ORIENTATION: laid flat (54 x 4 x 7 mm)
2. THINNEST WALL, WHOLE SOLID (RAY MINIMUM): 0.9210 mm ? a distance through material, NOT a printable wall where it falls on an edge, a fillet run-out or a chamfer tip. Printability is judged on the next line.
3. PRINTABLE MINIMUM WALL: 0.9236 mm (smallest median wall over a 1.1100 mm neighbourhood, cecad.inspect.printable_wall_detail) against a 0.8000 mm floor (2 perimeters @ 0.4 mm nozzle): VERDICT PASS
4. 2 horizontal bore(s) bridge at the crown: ream any bearing or press-fit bore to size
5. FILAMENT: PLA, ~1 g (modelled), 34 layers @ 0.2 mm
6. TOLERANCE BASIS, IN-HOUSE: CANNOT DETERMINE. Every Bambu on this farm records tolerance_mm: null, cite "no coupon printed and measured on this machine" (ce-machines/bambu-h2s-*, bambu-h2d-*/capabilities.json, read 2026-09-02), and Bambu Lab's own H2D Pro spec sheet carries no dimensional-accuracy line. DIMENSIONS HERE ARE NOMINAL AS MODELLED.
7. TOLERANCE BASIS, OUTSOURCED: JLC3DP ±0.3 mm FDM (jlc3dp.com, ce-machines/farm-jlc3dp); Hubs ±0.5%, floor ±0.5 mm (hubs.com/3d-printing/, ce-machines/farm-hubs). Apply the route's figure, not both. The ±0.2 mm in cecad/machining.py fdm is a repo planning constant with no vendor cite and is NOT used here. One printed and measured coupon closes this note.
8. NO ISO 286 CLASS IS DECLARED ON ANY BORE: FDM cannot be sized to one (H7/p6 at Ø3 is a 0.010 mm band). REAM bearing and press-fit bores after printing.
9. RADII NAMED IN cad/part.py THAT ARE NOT CIRCULAR EDGES ON THIS SOLID: 1.00 mm, 2.00 mm. cecad.inspect.arc_radii measures 1 ARC(S) HERE AND EVERY ONE IS DIMENSIONED ABOVE. NO DIMENSION IS MISSING: A LEADER NEEDS AN EDGE. THE GEOMETRY FILE CARRIES THE SURFACE.
10. ORTHOGRAPHIC VIEWS: 2 (FRONT, TOP) ? cecad.autosheet.choose_views ON
THE 54.015 x 3.800 x 6.626 mm BBOX, THIN/LONG 0.0704. A THIRD VIEW WOULD BE
THIS PART EDGE-ON, WHICH A.2 ORDERS SUPPRESSED; THE SECTION AND THE
ISOMETRIC CARRY IT.
FEATURE SCHEDULE ? 23 FEATURE(S) ENUMERATED OFF THE SOLID, GENERAL TOLERANCE CANNOT DETERMINE ? SEE PRINT / DFM NOTES

CENSUS cecad.sheetcheck.enumerate_features v2 ? 23 ROW(S), 6 CANNOT

DETERMINE, LISTED BELOW
OUTLINE ENVELOPE LENGTH
OUTLINE ENVELOPE WIDTH
OUTLINE ENVELOPE HEIGHT
HOLE 1 DIAMETER (ALONG Y)
HOLE 1 DEPTH
HOLE 1 POSITION FROM THE X DATUM FACE HOLE 1 POSITION FROM THE Z DATUM FACE HOLE 2 DIAMETER (ALONG Y)
HOLE 2 DEPTH
HOLE 2 POSITION FROM THE X DATUM FACE HOLE 2 POSITION FROM THE Z DATUM FACE
RADIUS R1.09 (4 EDGES, 4 FULL CIRCLES)
THINNEST WALL
POCKET MOUTH ON A PLANE NORMAL TO Y, 4 EDGE(S) ? WIDTH POCKET MOUTH ON A PLANE NORMAL TO Y, 4 EDGE(S) ? LENGTH POCKET MOUTH ON A PLANE NORMAL TO Y, 4 EDGE(S) ? DEPTH POCKET MOUTH ON A PLANE NORMAL TO Y, 4 EDGE(S) ? POSITIO POCKET MOUTH ON A PLANE NORMAL TO Y, 4 EDGE(S) ? POSITIO POCKET MOUTH ON A PLANE NORMAL TO Y, 4 EDGE(S) ? WIDTH POCKET MOUTH ON A PLANE NORMAL TO Y, 4 EDGE(S) ? LENGTH POCKET MOUTH ON A PLANE NORMAL TO Y, 4 EDGE(S) ? DEPTH
POCKET MOUTH ON A PLANE NORMAL TO Y, 4 EDGE(S) ? POSITIO
POCKET MOUTH ON A PLANE NORMAL TO Y, 4 EDGE(S) ? POSITIO
CANNOT DETERMINE ? FEATURES THIS CENSUS COULD NOT MEASURE (A4)

CANNOT DETERMINE ? CHAMFER: A4 requires size and angle on every chamfer; cecad.inspect has no chamfer classifier ? a chamfer is a planar face bridging two faces at an angle and nothing here identifies one. SETTLED BY: a chamfer classifier in cecad.inspect (planar face whose two neighbours meet it at equal angles), or the builder declaring its chamfers in the part record
CANNOT DETERMINE ? RIB: A4 requires thickness, height and pitch on every
rib; nothing here groups faces into a rib. SETTLED BY: a rib classifier (parallel thin prisms standing off a wall), or the builder declaring its rib pitch
CANNOT DETERMINE ? DRAFT: A4 requires every draft angle; no face here is tested for draft against a pull direction. SETTLED BY: a pull direction on the part record, then the angle of every planar face to it
CANNOT DETERMINE ? STEP: A4 requires every step and shoulder; nothing here classifies a shoulder between two coaxial diameters or two parallel faces. SETTLED BY: a step classifier, or the section views declaring their stations
CANNOT DETERMINE ? MATE: A4 requires every surface that mates with another part, with the mating part named by its triad ref; the mates live in ce-assemblies/*/joints.json and are not read here. SETTLED BY: reading this part's joints out of the assemblies that use it and matching each mate to a face
CANNOT DETERMINE ? WALL: A4 wants a wall thickness at every distinct
station; only the thinnest wall is measurable off the solid without a station list. SETTLED BY: the drawer declaring the section stations it dimensions, or a section per shell region
MICRODUCK-BANANA-PCB-LOCKER | | | | REV A
MATERIAL PLA | PROCESS FDM | SCALE 2:1
CATEGORY bracket | GENERAL TOL CANNOT DETER~ | FINISH AS PRINTED | SHEET A1 1/1
VOLUME (MEASURED) 0.46 cm3 | | MASS (ASSUMES PLA) 0.6 g | UNITS mm / deg
SIZE (BBOX, MEASURED) 54.02 x 3.80 x 6.63 | | DRAWN ce-cad 2026-09-05 | PROJECTION THIRD ANGLE

ce-parts/microduck-banana-pcb-locker/current/cad/part.py

1 | 2 | 3 | 4 | 5 | 6 | 7 | 8

### microduck-banana-pcb-locker SCALE 2:1 A1 THIRD ANGLE

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
E | E
D | D
C | C
B | B
A | A

SOURCE (DESIGN FILE)

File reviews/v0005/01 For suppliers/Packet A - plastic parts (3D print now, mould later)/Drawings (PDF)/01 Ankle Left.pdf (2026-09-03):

microduck-ankle-left | SCALE 5:1 | A1 | THIRD ANGLE

# ISOMETRIC VIEW

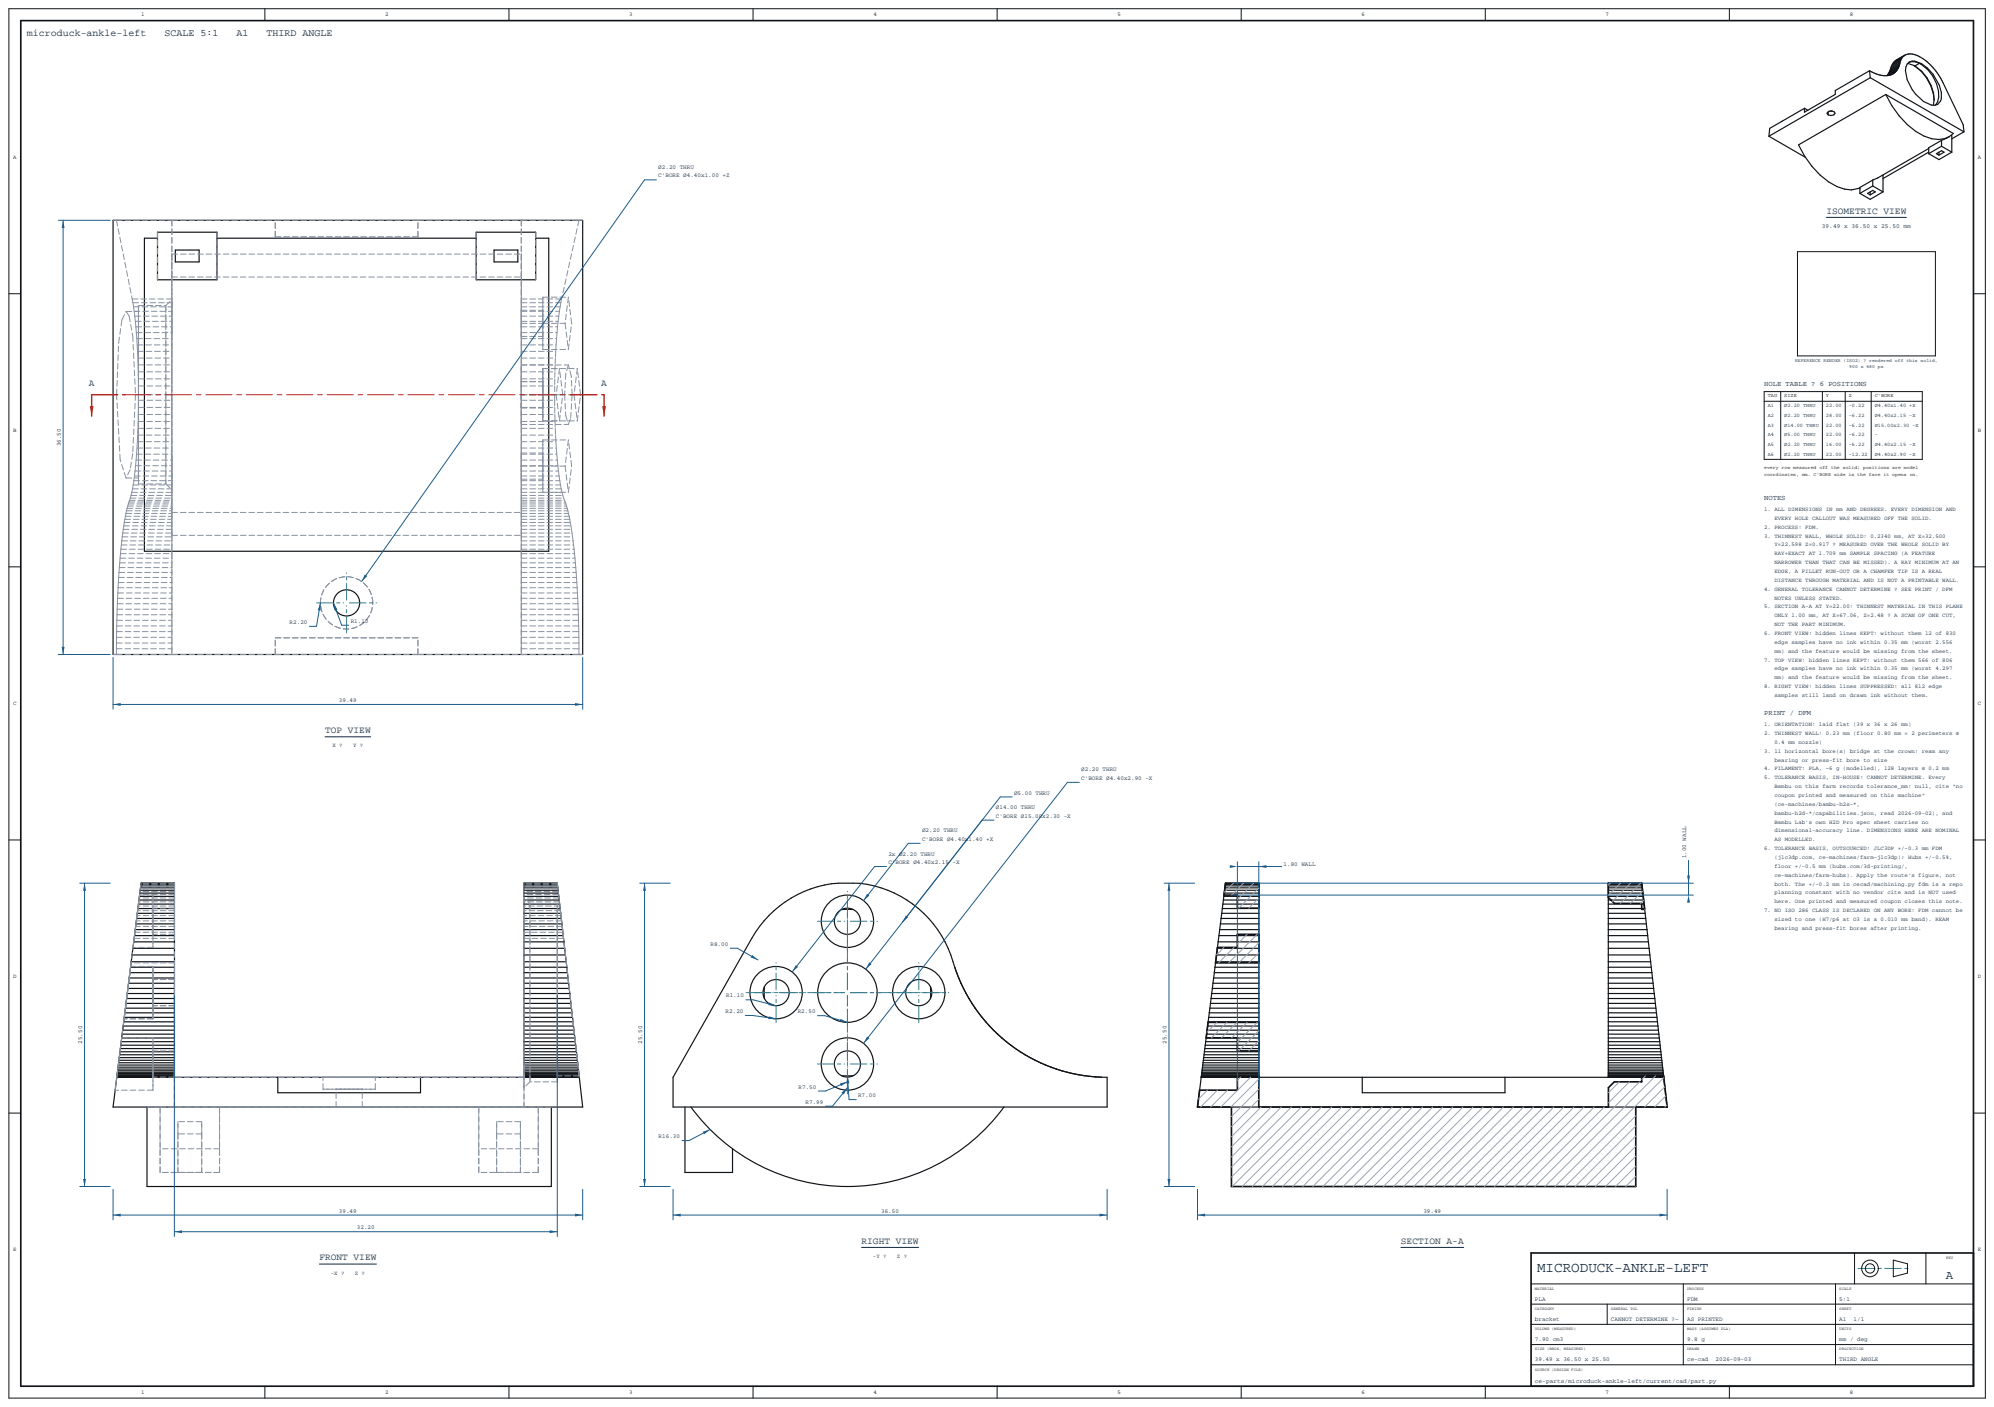
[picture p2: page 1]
FRONT VIEW; Ø2.20 THRU C'BORE Ø4.40x1.00 +Z; TOP VIEW; 2x Ø2.20 THRU C'BORE Ø4.40x2.15 -X; Ø2.20 THRU C'BORE Ø4.40x1.40 +X; Ø14.00 THRU C'BORE Ø15.00x2.30 -X; Ø5.00 THRU; Ø2.20 THRU C'BORE Ø4.40x2.90 -X; RIGHT VIEW; 1.00 WALL; 1.80 WALL; SECTION A-A; NOTES; PRINT / DFM

REFERENCE RENDER (ISO2) ? rendered off this solid,

HOLE TABLE ? 6 POSITIONS

TAG | SIZE | Y | Z | C'BORE
A1 A2 A3 A4 A5 A6 | Ø2.20 THRU Ø2.20 THRU Ø14.00 THRU Ø5.00 THRU Ø2.20 THRU Ø2.20 THRU | 22.00 28.00 22.00 22.00 16.00 22.00 | -0.22 -6.22 -6.22 -6.22 -6.22 -12.22 | Ø4.40x1.40 +X Ø4.40x2.15 -X Ø15.00x2.30 -X -Ø4.40x2.15 -X Ø4.40x2.90 -X

every row measured off the solid; positions are model
coordinates, mm. C'BORE side is the face it opens on.

1. ALL DIMENSIONS IN mm AND DEGREES. EVERY DIMENSION AND
EVERY HOLE CALLOUT WAS MEASURED OFF THE SOLID.
2. PROCESS: FDM.
3. THINNEST WALL, WHOLE SOLID: 0.2340 mm, AT X=32.500
Y=22.598 Z=0.917 ? MEASURED OVER THE WHOLE SOLID BY
RAY+EXACT AT 1.709 mm SAMPLE SPACING (A FEATURE
NARROWER THAN THAT CAN BE MISSED). A RAY MINIMUM AT AN
EDGE, A FILLET RUN-OUT OR A CHAMFER TIP IS A REAL
DISTANCE THROUGH MATERIAL AND IS NOT A PRINTABLE WALL.
4. GENERAL TOLERANCE CANNOT DETERMINE ? SEE PRINT / DFM
NOTES UNLESS STATED.
5. SECTION A-A AT Y=22.00: THINNEST MATERIAL IN THIS PLANE
ONLY 1.00 mm, AT X=67.06, Z=2.48 ? A SCAN OF ONE CUT,
NOT THE PART MINIMUM.
6. FRONT VIEW: hidden lines KEPT: without them 12 of 830
edge samples have no ink within 0.35 mm (worst 2.556
mm) and the feature would be missing from the sheet.
7. TOP VIEW: hidden lines KEPT: without them 566 of 806
edge samples have no ink within 0.35 mm (worst 4.297
8. RIGHT VIEW: hidden lines SUPPRESSED: all 812 edge
samples still land on drawn ink without them.

1. ORIENTATION: laid flat (39 x 36 x 26 mm)
2. THINNEST WALL: 0.23 mm (floor 0.80 mm = 2 perimeters @
0.4 mm nozzle)
3. 11 horizontal bore(s) bridge at the crown: ream any
bearing or press-fit bore to size
4. FILAMENT: PLA, ~6 g (modelled), 128 layers @ 0.2 mm
5. TOLERANCE BASIS, IN-HOUSE: CANNOT DETERMINE. Every
Bambu on this farm records tolerance_mm: null, cite "no
coupon printed and measured on this machine"
(ce-machines/bambu-h2s-*,
bambu-h2d-*/capabilities.json, read 2026-09-02), and
Bambu Lab's own H2D Pro spec sheet carries no
dimensional-accuracy line. DIMENSIONS HERE ARE NOMINAL
AS MODELLED.
6. TOLERANCE BASIS, OUTSOURCED: JLC3DP +/-0.3 mm FDM
(jlc3dp.com, ce-machines/farm-jlc3dp); Hubs +/-0.5%,
floor +/-0.5 mm (hubs.com/3d-printing/,
ce-machines/farm-hubs). Apply the route's figure, not
both. The +/-0.2 mm in cecad/machining.py fdm is a repo
planning constant with no vendor cite and is NOT used
here. One printed and measured coupon closes this note.
7. NO ISO 286 CLASS IS DECLARED ON ANY BORE: FDM cannot be
sized to one (H7/p6 at O3 is a 0.010 mm band). REAM
bearing and press-fit bores after printing.

MICRODUCK-ANKLE-LEFT | | | | REV A

MATERIAL PLA | PROCESS FDM | SCALE 5:1

CATEGORY bracket | GENERAL TOL CANNOT DETERMINE ?~ | FINISH AS PRINTED | SHEET A1 1/1

VOLUME (MEASURED) 7.90 cm3 | | MASS (ASSUMES PLA) 9.8 g | UNITS mm / deg

SIZE (BBOX, MEASURED) 39.49 x 36.50 x 25.50 | | DRAWN ce-cad 2026-09-03 | PROJECTION THIRD ANGLE

SOURCE (DESIGN FILE)
ce-parts/microduck-ankle-left/current/cad/part.py

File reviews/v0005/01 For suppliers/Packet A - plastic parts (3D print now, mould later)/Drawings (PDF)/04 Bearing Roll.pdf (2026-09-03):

# TOP VIEW

microduck-bearing-roll | SCALE 10:1 | A1 | THIRD ANGLE

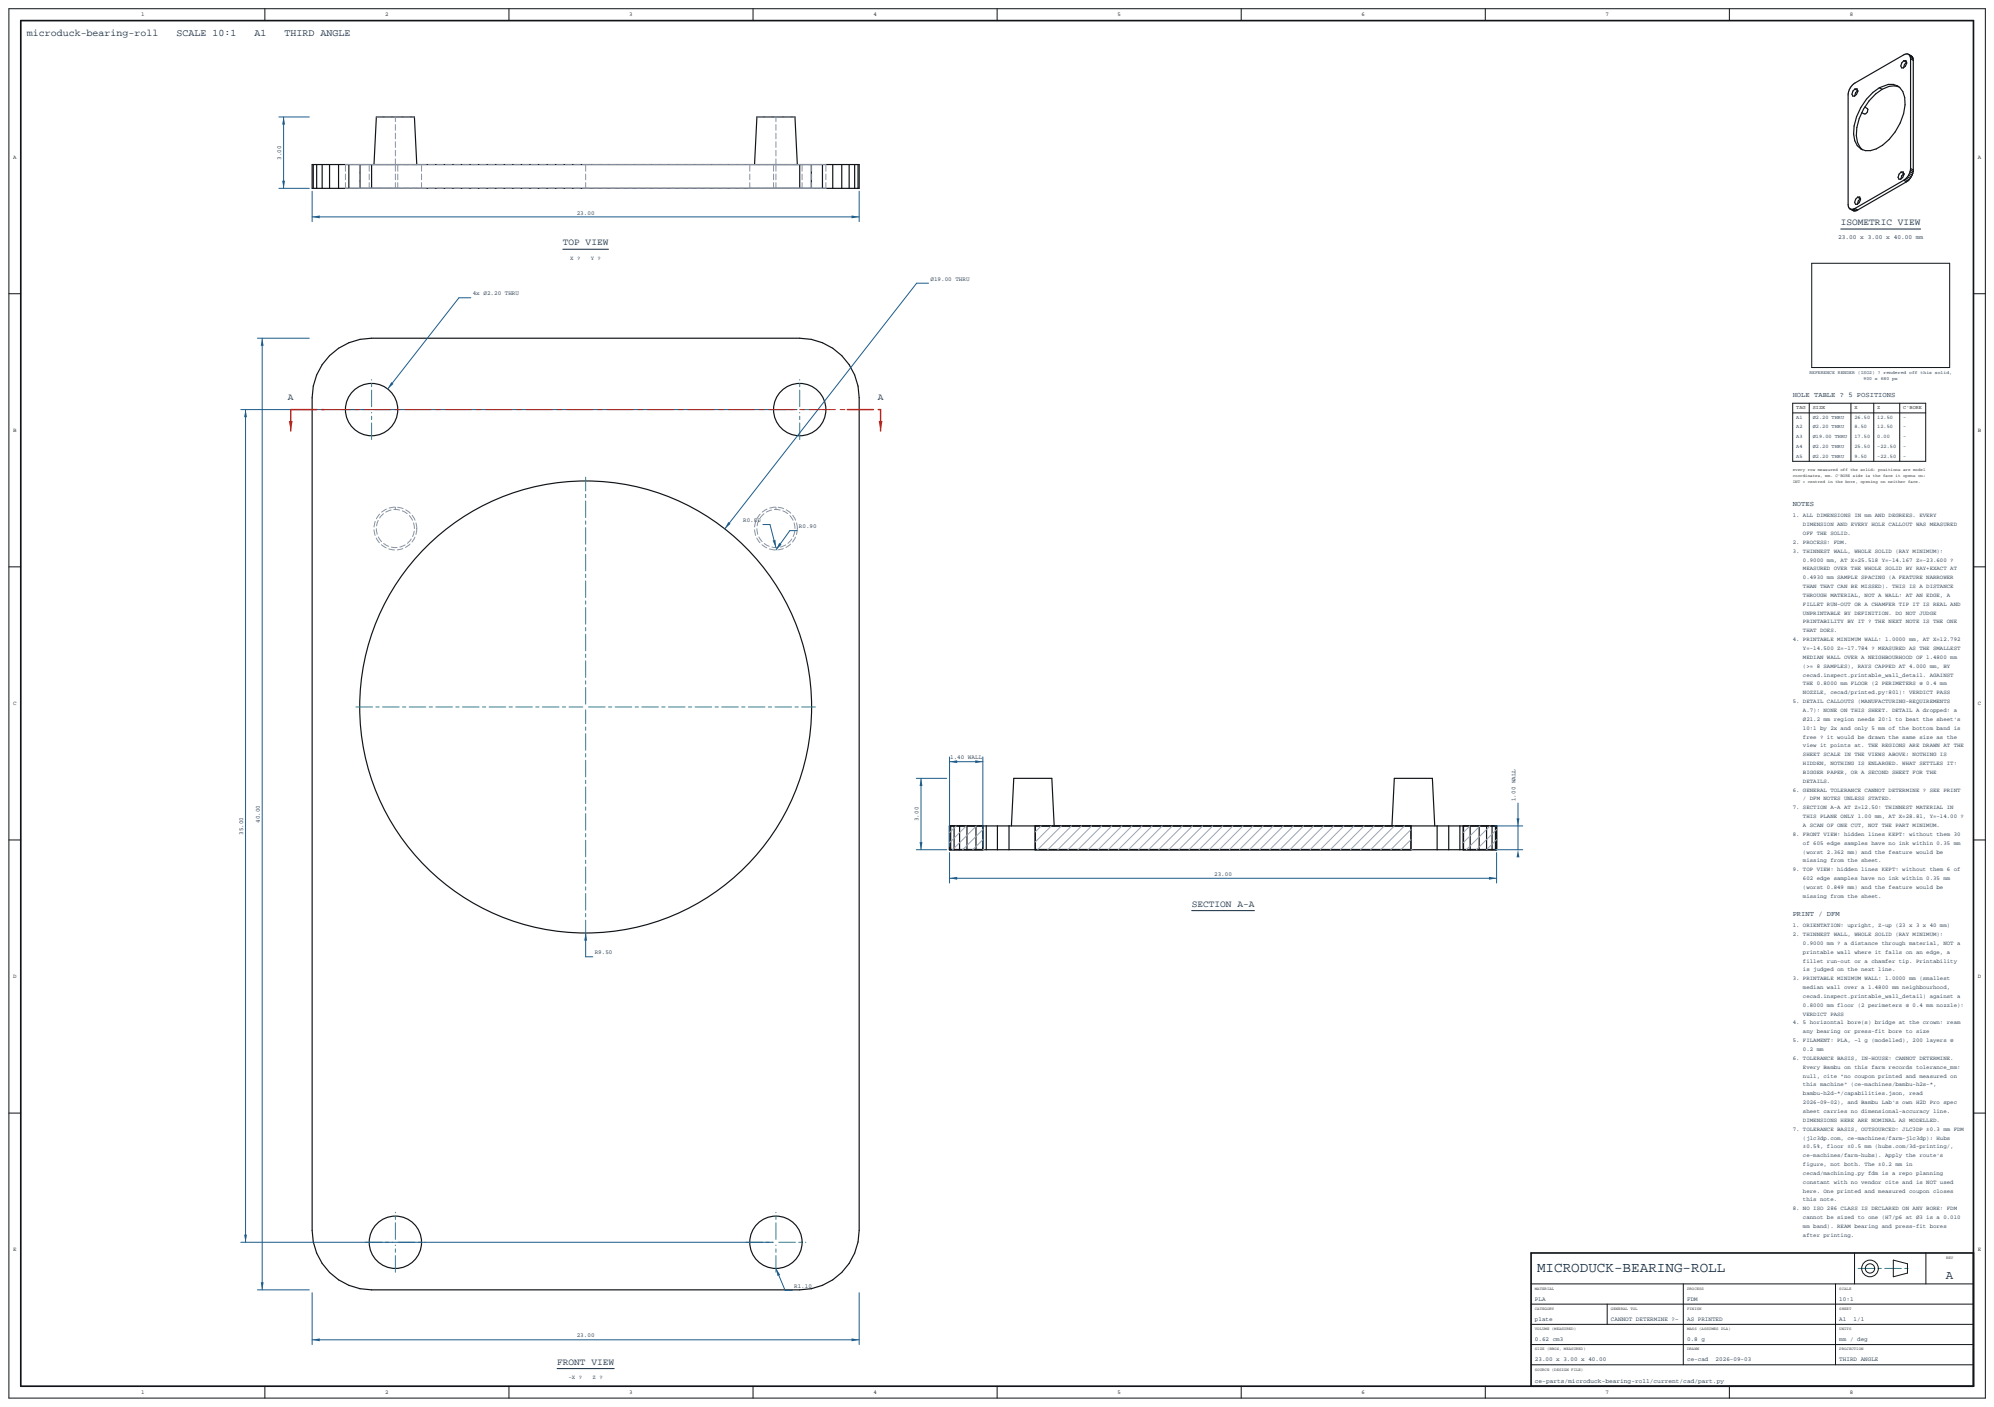
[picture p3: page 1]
4x Ø2.20 THRU; Ø19.00 THRU; FRONT VIEW; 1.00 WALL; 1.40 WALL; SECTION A-A; NOTES; PRINT / DFM

ISOMETRIC VIEW 23.00 x 3.00 x 40.00 mm

REFERENCE RENDER (ISO2) ? rendered off this solid,

HOLE TABLE ? 5 POSITIONS

TAG | SIZE | X | Z | C'BORE
A1 A2 A3 A4 A5 | Ø2.20 THRU Ø2.20 THRU Ø19.00 THRU Ø2.20 THRU Ø2.20 THRU | 26.50 8.50 17.50 25.50 9.50 | 12.50 12.50 0.00 -22.50 -22.50 | -----

every row measured off the solid; positions are model
coordinates, mm. C'BORE side is the face it opens on;
INT = centred in the bore, opening on neither face.

1. ALL DIMENSIONS IN mm AND DEGREES. EVERY
DIMENSION AND EVERY HOLE CALLOUT WAS MEASURED
OFF THE SOLID.
2. PROCESS: FDM.
3. THINNEST WALL, WHOLE SOLID (RAY MINIMUM):
MEASURED OVER THE WHOLE SOLID BY RAY+EXACT AT
0.4930 mm SAMPLE SPACING (A FEATURE NARROWER
THAN THAT CAN BE MISSED). THIS IS A DISTANCE
THROUGH MATERIAL, NOT A WALL: AT AN EDGE, A
FILLET RUN-OUT OR A CHAMFER TIP IT IS REAL AND
UNPRINTABLE BY DEFINITION. DO NOT JUDGE
PRINTABILITY BY IT ? THE NEXT NOTE IS THE ONE
THAT DOES.
4. PRINTABLE MINIMUM WALL: 1.0000 mm, AT X=12.792
Y=-14.500 Z=-17.784 ? MEASURED AS THE SMALLEST
MEDIAN WALL OVER A NEIGHBOURHOOD OF 1.4800 mm
(>= 8 SAMPLES), RAYS CAPPED AT 4.000 mm, BY
cecad.inspect.printable_wall_detail. AGAINST
THE 0.8000 mm FLOOR (2 PERIMETERS @ 0.4 mm
NOZZLE, cecad/printed.py:801): VERDICT PASS
5. DETAIL CALLOUTS (MANUFACTURING-REQUIREMENTS
A.7): NONE ON THIS SHEET. DETAIL A dropped: a
Ø21.2 mm region needs 20:1 to beat the sheet's
10:1 by 2x and only 5 mm of the bottom band is
free ? it would be drawn the same size as the
view it points at. THE REGIONS ARE DRAWN AT THE
SHEET SCALE IN THE VIEWS ABOVE; NOTHING IS
HIDDEN, NOTHING IS ENLARGED. WHAT SETTLES IT:
BIGGER PAPER, OR A SECOND SHEET FOR THE
DETAILS.
6. GENERAL TOLERANCE CANNOT DETERMINE ? SEE PRINT
/ DFM NOTES UNLESS STATED.
7. SECTION A-A AT Z=12.50: THINNEST MATERIAL IN
THIS PLANE ONLY 1.00 mm, AT X=28.81, Y=-14.00 ?
A SCAN OF ONE CUT, NOT THE PART MINIMUM.
8. FRONT VIEW: hidden lines KEPT: without them 30
of 605 edge samples have no ink within 0.35 mm
(worst 2.362 mm) and the feature would be
missing from the sheet.
9. TOP VIEW: hidden lines KEPT: without them 6 of
602 edge samples have no ink within 0.35 mm
(worst 0.849 mm) and the feature would be

1. ORIENTATION: upright, Z-up (23 x 3 x 40 mm)
2. THINNEST WALL, WHOLE SOLID (RAY MINIMUM):
0.9000 mm ? a distance through material, NOT a
printable wall where it falls on an edge, a
fillet run-out or a chamfer tip. Printability
is judged on the next line.
3. PRINTABLE MINIMUM WALL: 1.0000 mm (smallest
median wall over a 1.4800 mm neighbourhood,
cecad.inspect.printable_wall_detail) against a
0.8000 mm floor (2 perimeters @ 0.4 mm nozzle):
VERDICT PASS
4. 5 horizontal bore(s) bridge at the crown: ream
any bearing or press-fit bore to size
5. FILAMENT: PLA, ~1 g (modelled), 200 layers @
6. TOLERANCE BASIS, IN-HOUSE: CANNOT DETERMINE.
Every Bambu on this farm records tolerance_mm:
null, cite "no coupon printed and measured on
this machine" (ce-machines/bambu-h2s-*,
bambu-h2d-*/capabilities.json, read
2026-09-02), and Bambu Lab's own H2D Pro spec
sheet carries no dimensional-accuracy line.
DIMENSIONS HERE ARE NOMINAL AS MODELLED.
7. TOLERANCE BASIS, OUTSOURCED: JLC3DP ±0.3 mm FDM
(jlc3dp.com, ce-machines/farm-jlc3dp); Hubs
±0.5%, floor ±0.5 mm (hubs.com/3d-printing/,
ce-machines/farm-hubs). Apply the route's
figure, not both. The ±0.2 mm in
cecad/machining.py fdm is a repo planning
constant with no vendor cite and is NOT used
here. One printed and measured coupon closes
this note.
8. NO ISO 286 CLASS IS DECLARED ON ANY BORE: FDM
cannot be sized to one (H7/p6 at Ø3 is a 0.010
mm band). REAM bearing and press-fit bores
after printing.

MICRODUCK-BEARING-ROLL | | | | REV A

MATERIAL PLA | PROCESS FDM | SCALE 10:1

CATEGORY plate | GENERAL TOL CANNOT DETERMINE ?~ | FINISH AS PRINTED | SHEET A1 1/1

VOLUME (MEASURED) 0.62 cm3 | | MASS (ASSUMES PLA) 0.8 g | UNITS mm / deg

SIZE (BBOX, MEASURED) 23.00 x 3.00 x 40.00 | | DRAWN ce-cad 2026-09-03 | PROJECTION THIRD ANGLE

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

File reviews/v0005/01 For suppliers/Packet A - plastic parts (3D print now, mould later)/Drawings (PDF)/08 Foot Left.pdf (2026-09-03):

40.09

16.91

# FRONT VIEW

-X ? Z ?

40.09

54.00

Ø1.60 THRU
C'BORE Ø3.00x0.50 +Z
R1.50 | R2.50 R0.80

# TOP VIEW

X ? Y ?

54.00

16.91

# RIGHT VIEW

-Y ? Z ?

54.00

16.90

0.72 WALL

2.50 WALL

# SECTION A-A

# ISOMETRIC VIEW

40.09 x 54.00 x 16.91 mm

A

A

REFERENCE RENDER (ISO2) ? rendered off this solid, 900 x 680 px

### NOTES

1. ALL DIMENSIONS IN mm AND DEGREES. EVERY DIMENSION AND EVERY HOLE CALLOUT WAS MEASURED OFF THE SOLID.
2. PROCESS: FDM.
3. THINNEST WALL, WHOLE SOLID: 0.0150 mm, AT X=46.400 Y=34.526 Z=-16.651 ? MEASURED OVER THE WHOLE SOLID BY RAY+EXACT AT 1.477 mm SAMPLE SPACING (A FEATURE NARROWER THAN THAT CAN BE MISSED). A RAY MINIMUM AT AN EDGE, A FILLET RUN-OUT OR A CHAMFER TIP IS A REAL DISTANCE THROUGH MATERIAL AND IS NOT A PRINTABLE WALL.
4. GENERAL TOLERANCE CANNOT DETERMINE ? SEE PRINT / DFM NOTES UNLESS STATED.
5. SECTION A-A AT X=50.00: THINNEST MATERIAL IN THIS PLANE ONLY 0.72 mm, AT Y=37.12, Z=-14.38 ? A SCAN OF ONE CUT, NOT THE PART MINIMUM.
6. FRONT VIEW: hidden lines KEPT: without them 3 of 2745 edge samples have no ink within 0.35 mm (worst 0.458 mm) and the feature would be missing from the sheet.
7. TOP VIEW: hidden lines KEPT: without them 218 of 2952 edge samples have no ink within 0.35 mm (worst 1.029 mm) and the feature would be missing from the sheet.
8. RIGHT VIEW: hidden lines KEPT: without them 27 of 2759 edge samples have no ink within 0.35 mm (worst 0.721 mm) and the feature would be missing from the sheet.

### PRINT / DFM

1. ORIENTATION: laid flat (40 x 54 x 17 mm)
2. THINNEST WALL: 0.01 mm (floor 0.80 mm = 2 perimeters @ 0.4 mm nozzle)
3. SMALL HOLES O1.60 PRINT UNDERSIZE: drill to tapping size and form-tap after printing; heat-set inserts for M2 into PLA
4. FILAMENT: PLA, ~14 g (modelled), 85 layers @ 0.2 mm
5. TOLERANCE BASIS, IN-HOUSE: CANNOT DETERMINE. Every Bambu on this farm records tolerance_mm: null, cite "no coupon printed and measured on this machine" (ce-machines/bambu-h2s-*,
bambu-h2d-*/capabilities.json, read 2026-09-02), and Bambu Lab's own H2D Pro spec sheet carries no dimensional-accuracy line. DIMENSIONS HERE ARE NOMINAL AS MODELLED.
6. TOLERANCE BASIS, OUTSOURCED: JLC3DP +/-0.3 mm FDM (jlc3dp.com, ce-machines/farm-jlc3dp); Hubs +/-0.5%, floor +/-0.5 mm (hubs.com/3d-printing/, ce-machines/farm-hubs). Apply the route's figure, not both. The +/-0.2 mm in cecad/machining.py fdm is a repo planning constant with no vendor cite and is NOT used here. One printed and measured coupon closes this note.
7. NO ISO 286 CLASS IS DECLARED ON ANY BORE: FDM cannot be sized to one (H7/p6 at O3 is a 0.010 mm band). REAM bearing and press-fit bores after printing.

# MICRODUCK-FOOT-LEFT

A

PLA | | FDM | 2:1
robot-link | CANNOT DETERMINE ?~ | AS PRINTED | A2 1/1
11.74 cm3 | | 14.6 g | mm / deg
40.09 x 54.00 x 16.91 | | ce-cad 2026-09-03 | THIRD ANGLE

ce-parts/microduck-foot-left/current/cad/part.py

microduck-foot-left | SCALE 2:1 | A2 | THIRD ANGLE
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
D | D
C | C
B | B
A | A

REV

MATERIAL | PROCESS | SCALE
CATEGORY | GENERAL TOL | FINISH | SHEET
VOLUME (MEASURED) | MASS (ASSUMES PLA) | UNITS
SIZE (BBOX, MEASURED) | DRAWN | PROJECTION

SOURCE (DESIGN FILE)

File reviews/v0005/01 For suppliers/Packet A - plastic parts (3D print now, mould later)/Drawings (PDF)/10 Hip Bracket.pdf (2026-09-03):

# ISOMETRIC VIEW

### 32.45 x 34.50 x 19.00 mm

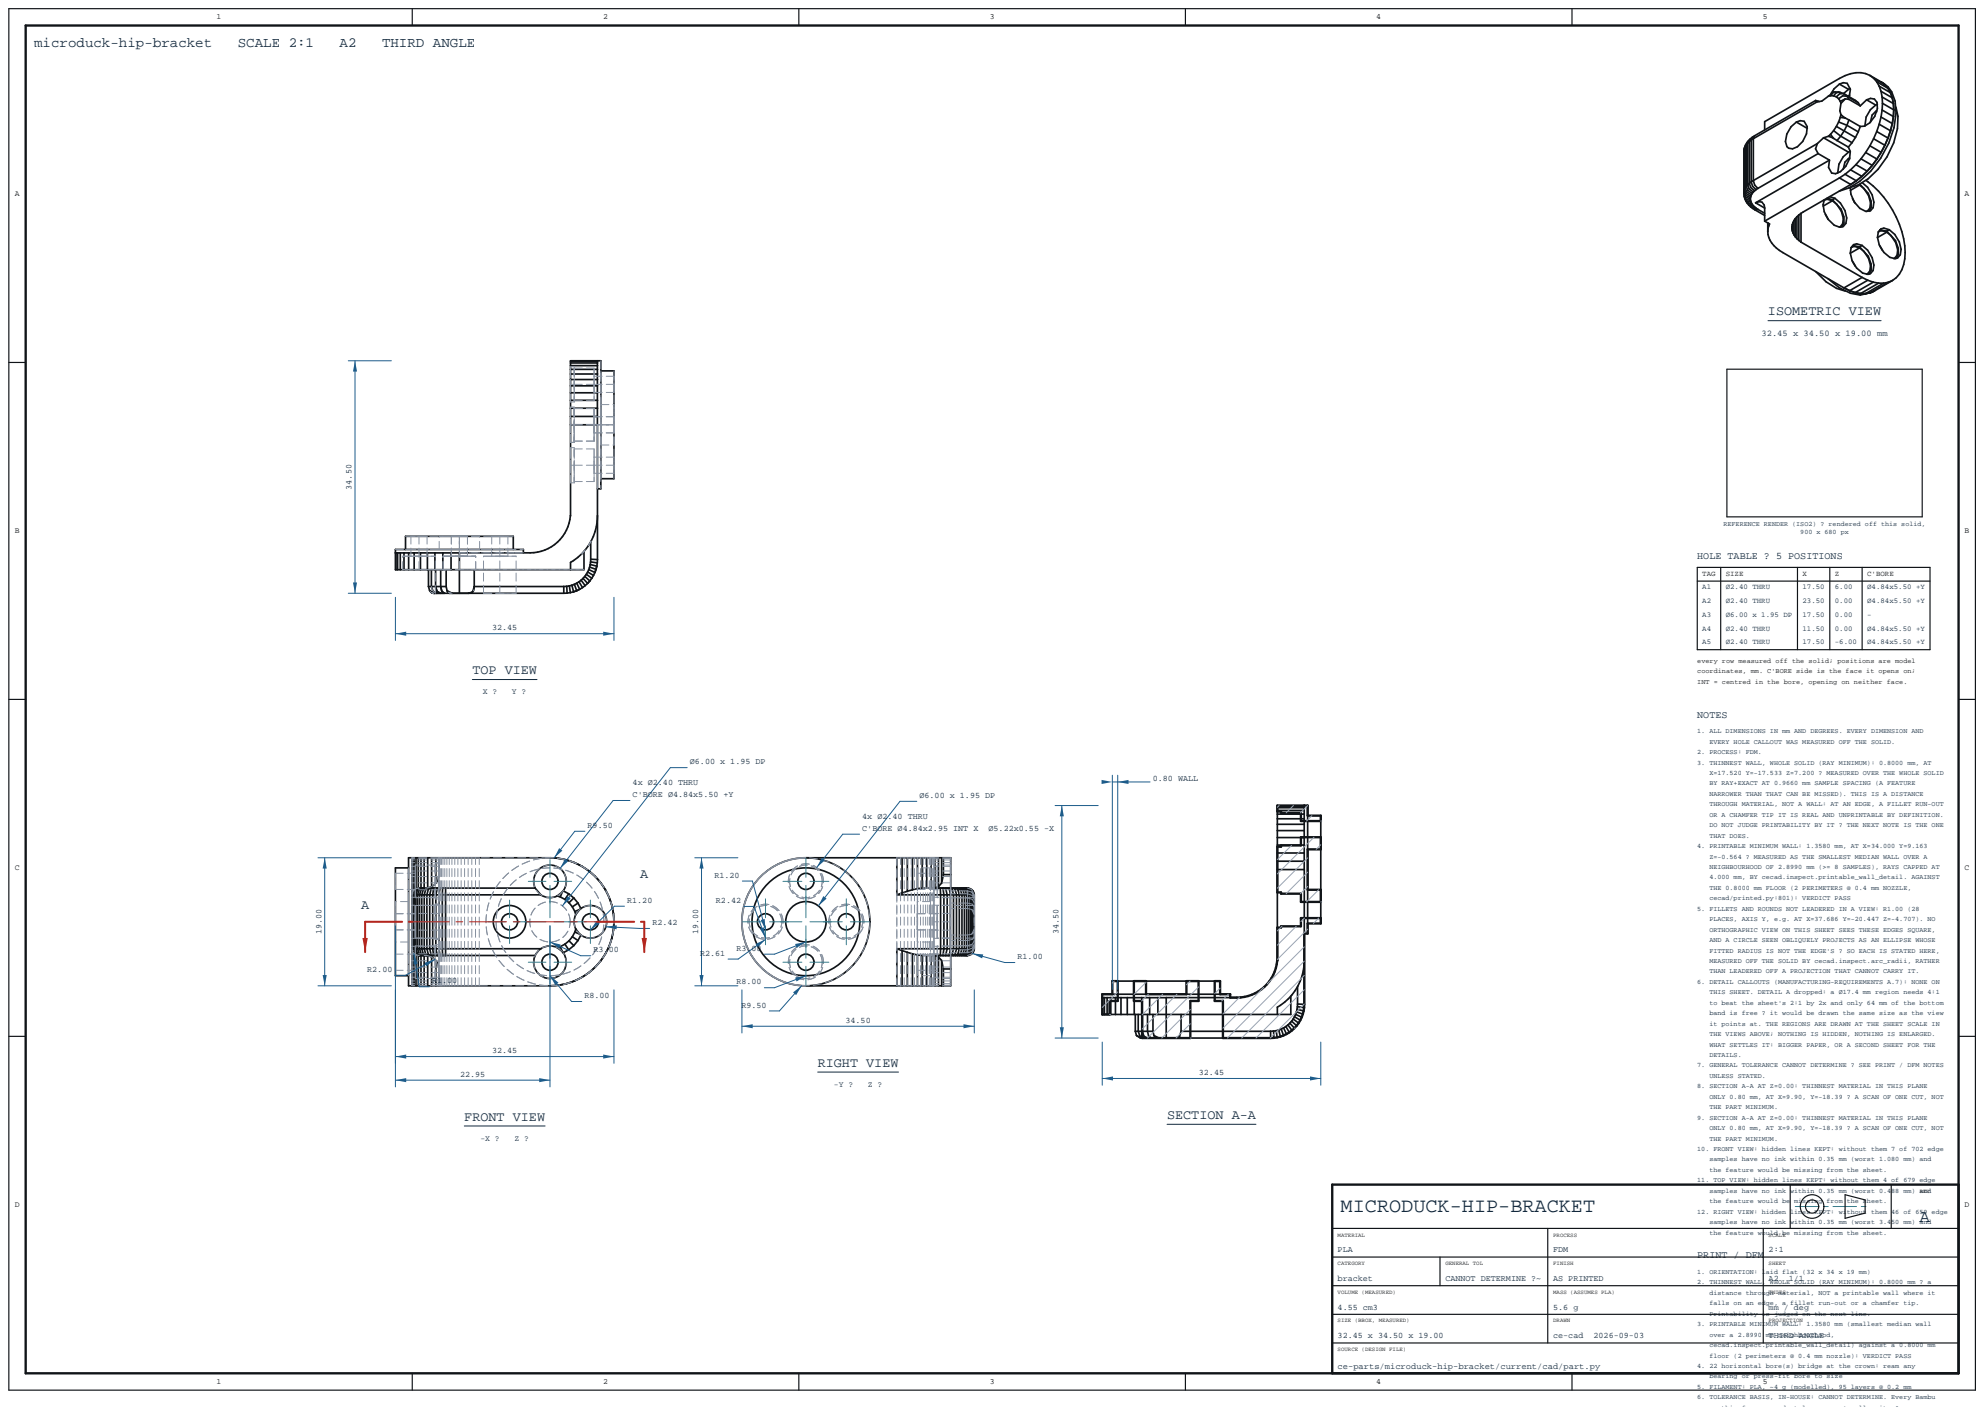
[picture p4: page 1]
4x Ø2.40 THRU C'BORE Ø4.84x5.50 +Y; FRONT VIEW; TOP VIEW; 4x Ø2.40 THRU C'BORE Ø4.84x2.95 INT X Ø5.22x0.55 -X; RIGHT VIEW; 0.80 WALL; SECTION A-A; NOTES; samples have no ink; within 0.35 mm (worst 0.488 mm) and; the feature would be; missing from; the sheet.; 12. RIGHT VIEW: hidden; lines KEPT: without them; 46 of 659 edge; within 0.35 mm (worst 3.450 mm) and; microduck-hip-bracket; SCALE 2:1; THIRD ANGLE; REV

REFERENCE RENDER (ISO2) ? rendered off this solid,

HOLE TABLE ? 5 POSITIONS

TAG | SIZE | X | Z | C'BORE
A1 A2 A3 A4 A5 | Ø2.40 THRU Ø2.40 THRU Ø6.00 x 1.95 DP Ø2.40 THRU Ø2.40 THRU | 17.50 23.50 17.50 11.50 17.50 | 6.00 0.00 0.00 0.00 -6.00 | Ø4.84x5.50 +Y Ø4.84x5.50 +Y -Ø4.84x5.50 +Y Ø4.84x5.50 +Y

every row measured off the solid; positions are model
coordinates, mm. C'BORE side is the face it opens on;
INT = centred in the bore, opening on neither face.

1. ALL DIMENSIONS IN mm AND DEGREES. EVERY DIMENSION AND
EVERY HOLE CALLOUT WAS MEASURED OFF THE SOLID.
2. PROCESS: FDM.
3. THINNEST WALL, WHOLE SOLID (RAY MINIMUM): 0.8000 mm, AT
X=17.520 Y=-17.533 Z=7.200 ? MEASURED OVER THE WHOLE SOLID
BY RAY+EXACT AT 0.9660 mm SAMPLE SPACING (A FEATURE
NARROWER THAN THAT CAN BE MISSED). THIS IS A DISTANCE
THROUGH MATERIAL, NOT A WALL: AT AN EDGE, A FILLET RUN-OUT
OR A CHAMFER TIP IT IS REAL AND UNPRINTABLE BY DEFINITION.
DO NOT JUDGE PRINTABILITY BY IT ? THE NEXT NOTE IS THE ONE
THAT DOES.
4. PRINTABLE MINIMUM WALL: 1.3580 mm, AT X=34.000 Y=9.163
Z=-0.564 ? MEASURED AS THE SMALLEST MEDIAN WALL OVER A
NEIGHBOURHOOD OF 2.8990 mm (>= 8 SAMPLES), RAYS CAPPED AT
4.000 mm, BY cecad.inspect.printable_wall_detail. AGAINST
THE 0.8000 mm FLOOR (2 PERIMETERS @ 0.4 mm NOZZLE,
cecad/printed.py:801): VERDICT PASS
5. FILLETS AND ROUNDS NOT LEADERED IN A VIEW: R1.00 (28
PLACES, AXIS Y, e.g. AT X=37.686 Y=-20.447 Z=-4.707). NO
ORTHOGRAPHIC VIEW ON THIS SHEET SEES THESE EDGES SQUARE,
AND A CIRCLE SEEN OBLIQUELY PROJECTS AS AN ELLIPSE WHOSE
FITTED RADIUS IS NOT THE EDGE'S ? SO EACH IS STATED HERE,
MEASURED OFF THE SOLID BY cecad.inspect.arc_radii, RATHER
THAN LEADERED OFF A PROJECTION THAT CANNOT CARRY IT.
6. DETAIL CALLOUTS (MANUFACTURING-REQUIREMENTS A.7): NONE ON
THIS SHEET. DETAIL A dropped: a Ø17.4 mm region needs 4:1
to beat the sheet's 2:1 by 2x and only 64 mm of the bottom
band is free ? it would be drawn the same size as the view
it points at. THE REGIONS ARE DRAWN AT THE SHEET SCALE IN
THE VIEWS ABOVE; NOTHING IS HIDDEN, NOTHING IS ENLARGED.
WHAT SETTLES IT: BIGGER PAPER, OR A SECOND SHEET FOR THE
DETAILS.
7. GENERAL TOLERANCE CANNOT DETERMINE ? SEE PRINT / DFM NOTES
UNLESS STATED.

8. SECTION A-A AT Z=0.00: THINNEST MATERIAL IN THIS PLANE
ONLY 0.80 mm, AT X=9.90, Y=-18.39 ? A SCAN OF ONE CUT, NOT
THE PART MINIMUM.
9. SECTION A-A AT Z=0.00: THINNEST MATERIAL IN THIS PLANE
10. FRONT VIEW: hidden lines KEPT: without them 7 of 702 edge
samples have no ink within 0.35 mm (worst 1.080 mm) and
the feature would be missing from the sheet.
11. TOP VIEW: hidden lines KEPT: without them 4 of 679 edge

MICRODUCK-HIP-BRACKET

MATERIAL PLA | the feature would be missing from the sheet. PROCESS FDM PRINT / DFM | SCALE 2:1

CATEGORY bracket | GENERAL TOL CANNOT DETERMINE ?~ | FINISH 1. ORIENTATION: AS PRINTED 2. THINNEST WALL, WHOLE SOLID (RAY MINIMUM): 0.8000 mm ? a | SHEET laid flat (32 x 34 x 19 mm) A2 1/1

VOLUME (MEASURED) 4.55 cm3 | | MASS (ASSUMES PLA) distance through material, NOT a printable wall where it falls on an edge, a fillet run-out or a chamfer tip. 5.6 g Printability | UNITS mm / deg is judged on the next line.

SIZE (BBOX, MEASURED) 32.45 x 34.50 x 19.00 | | DRAWN 3. PRINTABLE MINIMUM WALL: 1.3580 mm (smallest median wall ce-cad 2026-09-03 over a 2.8990 | PROJECTION mm neighbourhood, THIRD ANGLE

SOURCE (DESIGN FILE)
ce-parts/microduck-hip-bracket/current/cad/part.py

cecad.inspect.printable_wall_detail) against a 0.8000 mm
floor (2 perimeters @ 0.4 mm nozzle): VERDICT PASS
4. 22 horizontal bore(s) bridge at the crown: ream any
bearing or press-fit bore to size
5. FILAMENT: PLA, ~4 g (modelled), 95 layers @ 0.2 mm
6. TOLERANCE BASIS, IN-HOUSE: CANNOT DETERMINE. Every Bambu
on this farm records tolerance_mm: null, cite "no coupon

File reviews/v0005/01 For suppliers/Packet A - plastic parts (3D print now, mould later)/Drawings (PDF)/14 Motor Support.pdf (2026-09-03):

73.50

18.80

R11.10

R9.50

39.50

# FRONT VIEW

-X ? Z ?

73.50

54.20

9.50

49.20

9.50

10.20

48.85

3.20

58.50

45.70

4x Ø2.70 THRU

R1.35

# TOP VIEW

X ? Y ?

54.20

18.80

Ø17.65 THRU

R8.82

R7.50

# RIGHT VIEW

-Y ? Z ?

47.67

18.80

1.70 WALL

2.32 WALL

# SECTION A-A

# ISOMETRIC VIEW

73.50 x 54.20 x 18.80 mm

R11.10

R9.50

# DETAIL A

### SCALE 5:1

A

A

A

REFERENCE RENDER (ISO2) ? rendered off this solid, 900 x 680 px

### NOTES
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

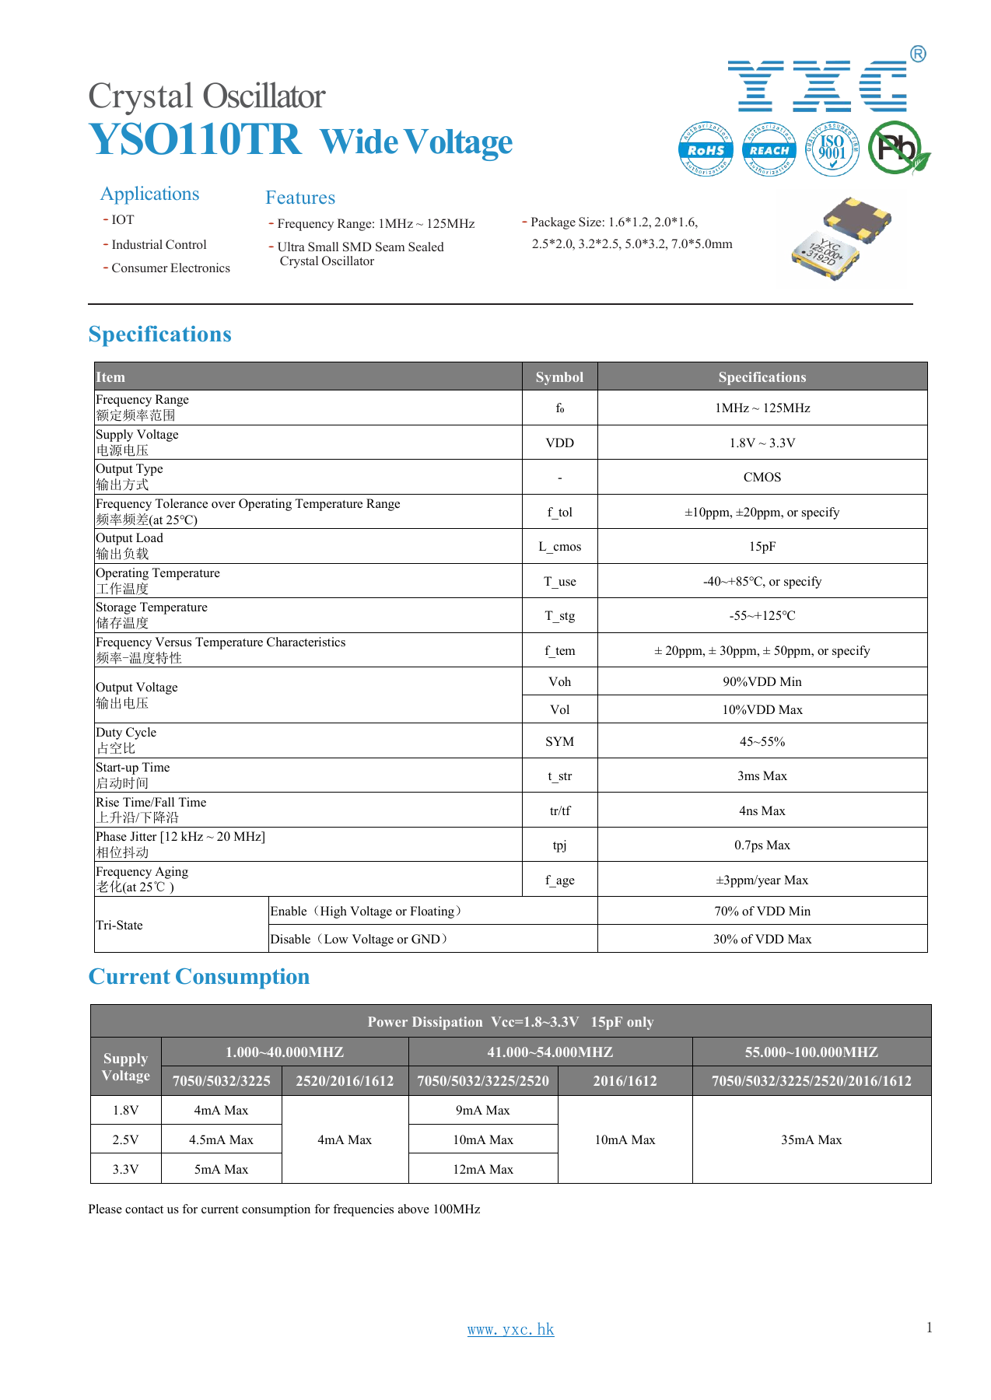
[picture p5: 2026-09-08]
ce-parts/microduck-public-hat-y1/docs/yxc-page-1.png

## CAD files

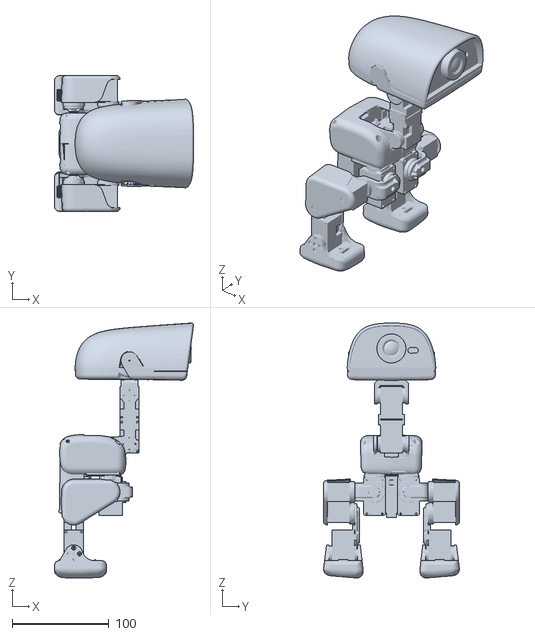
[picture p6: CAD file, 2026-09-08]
research/mesh-repair-2026-09-09/Microduck-Review-F/01 See the robot/Whole robot - view only.stl
144.1 x 141.0 x 264.0

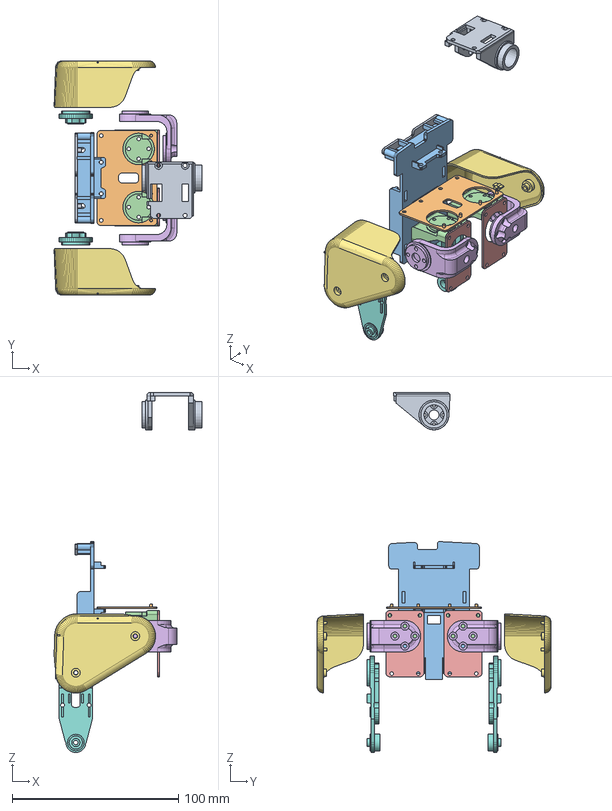
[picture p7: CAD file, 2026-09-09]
reviews/v0004/00 Open in your own software/Microduck - assembly.step
88.8 x 141.0 x 216.6 mm
trunk_base/microduck-banana-pcb-locker#2
trunk_base/microduck-trunk-base#3
trunk_base/microduck-power-support#5
yaw2roll/microduck-yaw2roll#10
yaw2roll/microduck-bearing-roll#13
hip_l/microduck-hip-bracket#15
upper_leg_left/microduck-upper-leg-left#16
leg/microduck-shin#21
yaw_roll_motion/microduck-yaw-roll-motion#33
bearing_roll/microduck-yaw2roll#53
bearing_roll/microduck-bearing-roll#55
hip_l_2/microduck-hip-bracket#57
upper_leg_right/microduck-upper-leg-right#62
leg_2/microduck-shin#65

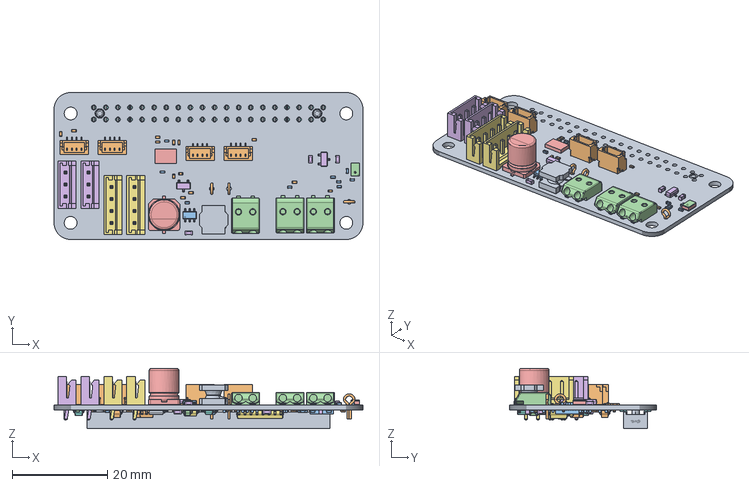
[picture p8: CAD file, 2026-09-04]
reviews/v0005/01 For suppliers/Packet E - PCB fab and SMT (quote only, not released)/P1 Robot HAT assembled board (STEP, reference).step
65.0 x 30.9 x 12.7 mm

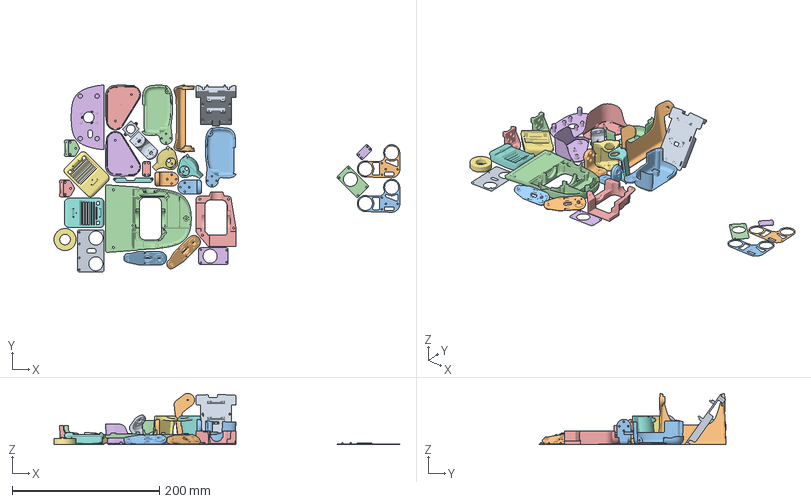
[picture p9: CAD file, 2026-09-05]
research/mesh-repair-2026-09-09/Microduck-Review-F/07 Files for the engineer/Project files/out/print/plates/X1C/microduck-PLA-X1C-main.3mf
470.5 x 254.0 x 69.7 mm
microduck-power-support.stl
microduck-jaw.stl
microduck-trunk-shell-right.stl
microduck-trunk-shell-left.stl
microduck-upper-leg-right.stl
microduck-upper-leg-left.stl
microduck-ankle-left.stl
microduck-ankle-right.stl
microduck-neck-pitch-bracket.stl
microduck-hip-bracket.stl x 2
microduck-bottom-head-shell.stl
microduck-motor-support.stl
microduck-face-part.stl
microduck-foot-left.stl
microduck-foot-right.stl
microduck-trunk-base.stl
microduck-shin.stl x 2
microduck-yaw2roll.stl x 2
microduck-bearing-roll.stl x 2
microduck-eye-ring.stl
microduck-banana-pcb-locker.stl
microduck-m12-lens-holder.stl
microduck-upper-leg-rigidity-plate.stl x 2
microduck-neck-plate.stl x 2

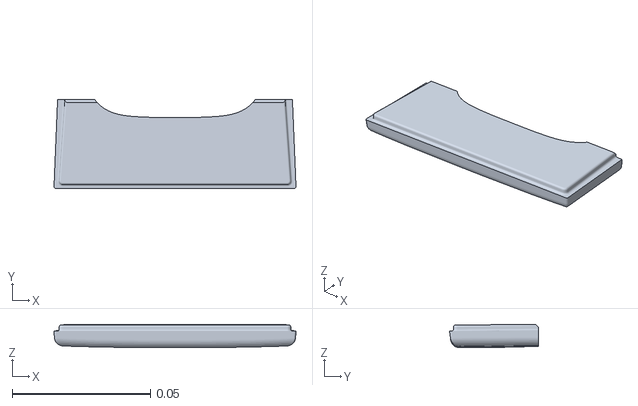
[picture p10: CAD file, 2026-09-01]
ce-parts/microduck-jaw-soft/iterations/v0.0.1/geometry/jaw_soft.stl
0.0877 x 0.0322 x 0.00844

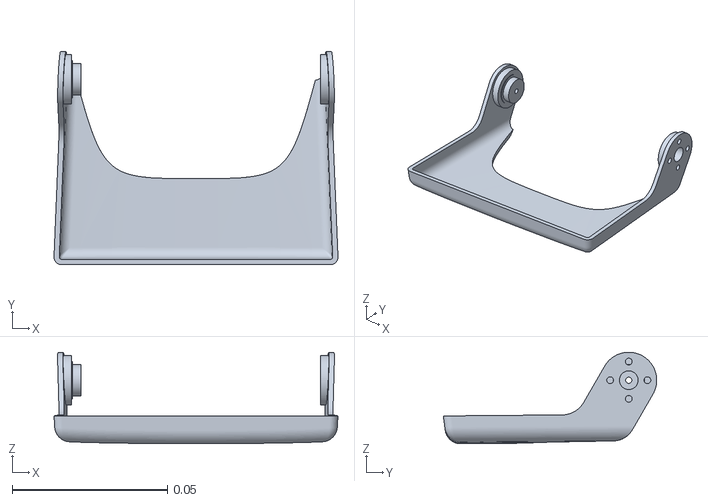
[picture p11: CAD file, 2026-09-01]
ce-parts/microduck-jaw/iterations/v0.0.1/geometry/jaw.stl
0.0914 x 0.0687 x 0.0294

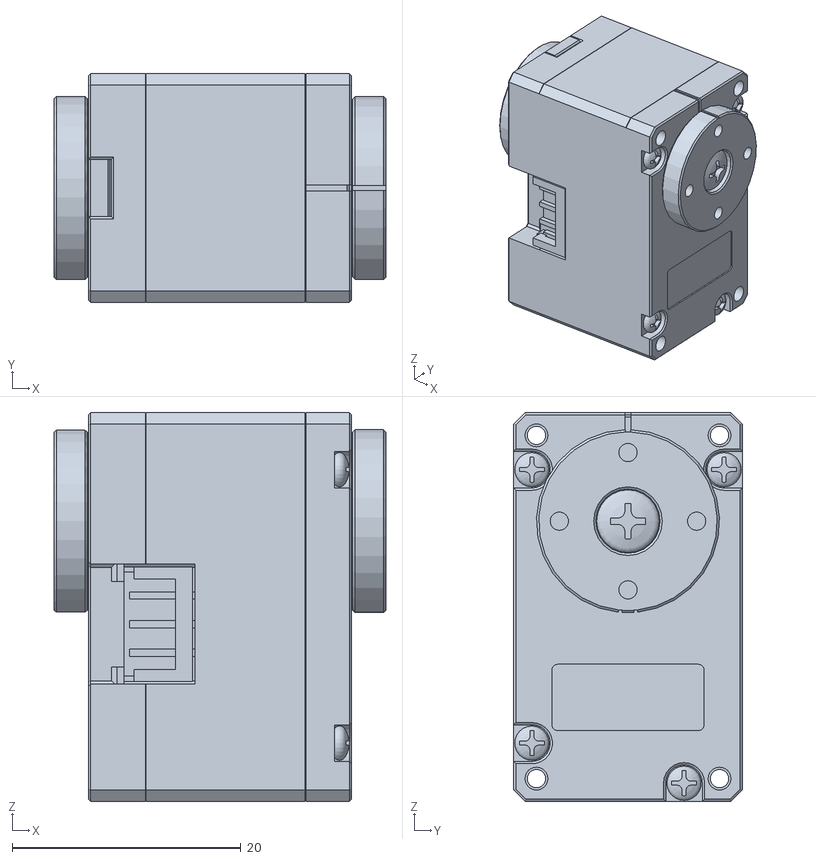
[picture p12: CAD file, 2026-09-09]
out/fit/vendor-xl330-local.stl
29.0 x 20.0 x 34.0

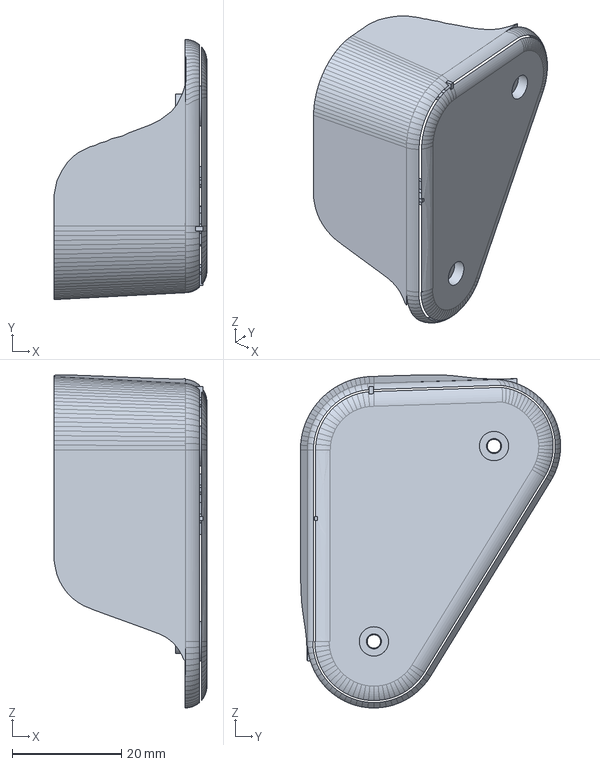
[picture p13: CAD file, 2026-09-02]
out/stress/microduck-upper-leg-left_landing_PLA/microduck-upper-leg-left.step
28.0 x 47.7 x 61.0 mm

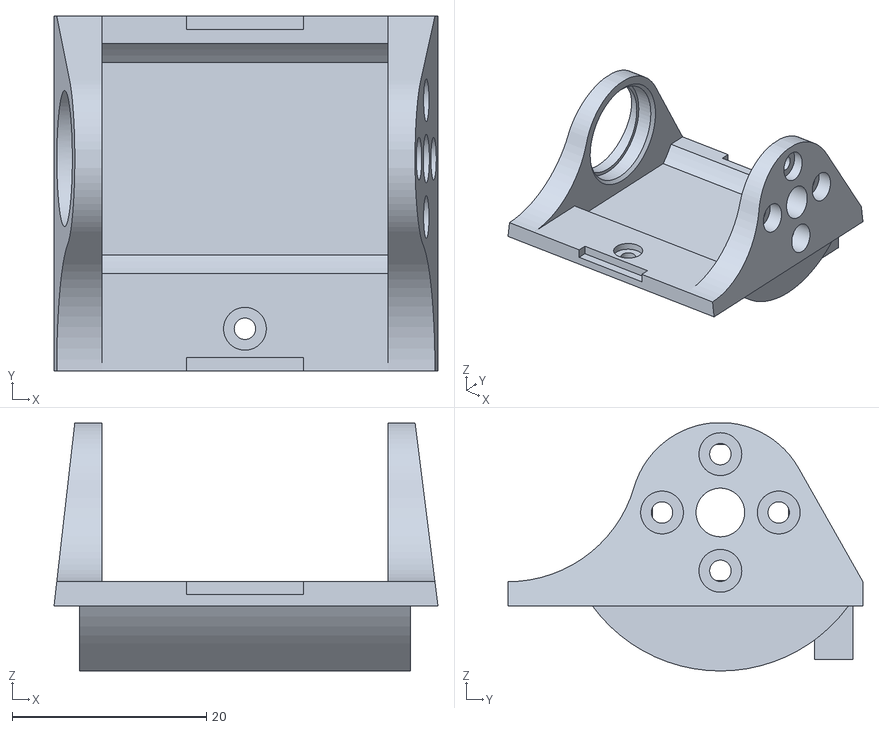
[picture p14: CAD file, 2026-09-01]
research/mesh-repair-2026-09-09/Microduck-Review-F/02 Look at the parts/01 Ankle Left/Ankle Left.stl
39.5 x 36.5 x 25.5

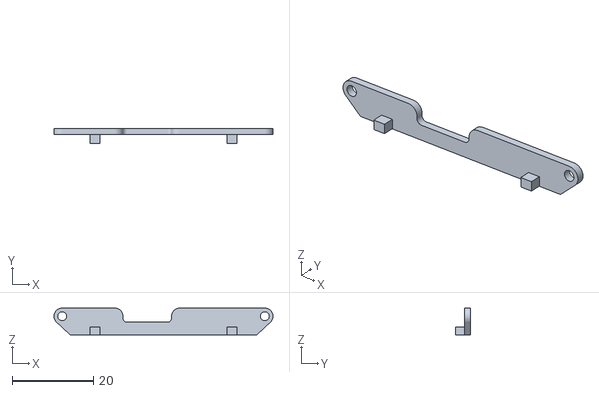
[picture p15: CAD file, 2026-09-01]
research/mesh-repair-2026-09-09/Microduck-Review-F/02 Look at the parts/03 Banana Pcb Locker/Banana Pcb Locker.stl
54.0 x 3.80 x 6.63

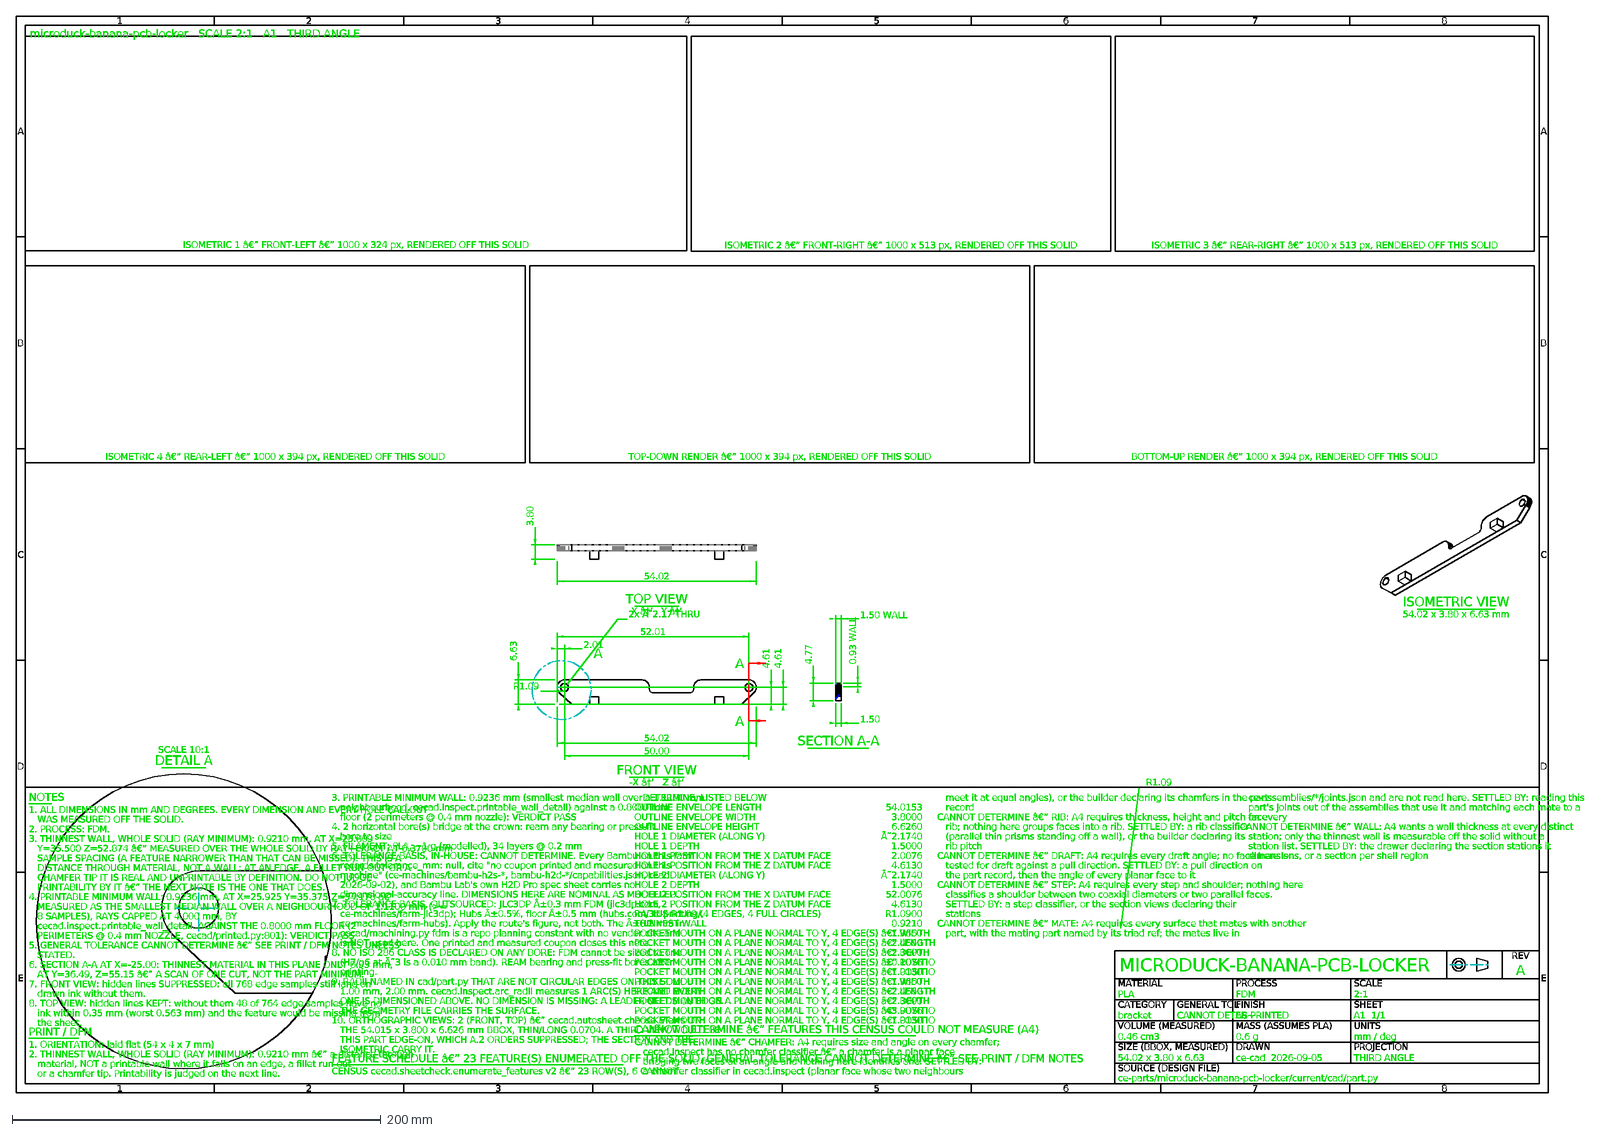
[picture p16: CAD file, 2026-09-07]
research/mesh-repair-2026-09-09/Microduck-Review-F/02 Look at the parts/03 Banana Pcb Locker/Drawings and details/microduck-banana-pcb-locker.dxf
1
2
3
4
5
6
7
8
E
D
C
B
A
54.02
6.63
2.01
4.61
52.01
2x Ã˜2.17 THRU
R1.09
50.00
FRONT VIEW
-X â†’ Z â†‘
3.80
TOP VIEW
X â†’ Y â†‘
1.50
4.77
0.93 WALL
1.50 WALL
SECTION A-A
ISOMETRIC VIEW
54.02 x 3.80 x 6.63 mm
DETAIL A
SCALE 10:1
ISOMETRIC 1 â€” FRONT-LEFT â€” 1000 x 324 px, RENDERED OFF THIS SOLID
ISOMETRIC 2 â€” FRONT-RIGHT â€” 1000 x 513 px, RENDERED OFF THIS SOLID
ISOMETRIC 3 â€” REAR-RIGHT â€” 1000 x 513 px, RENDERED OFF THIS SOLID
ISOMETRIC 4 â€” REAR-LEFT â€” 1000 x 394 px, RENDERED OFF THIS SOLID
TOP-DOWN RENDER â€” 1000 x 394 px, RENDERED OFF THIS SOLID
BOTTOM-UP RENDER â€” 1000 x 394 px, RENDERED OFF THIS SOLID
NOTES
1. ALL DIMENSIONS IN mm AND DEGREES. EVERY DIMENSION AND EVERY HOLE CALLOUT
WAS MEASURED OFF THE SOLID.
2. PROCESS: FDM.
3. THINNEST WALL, WHOLE SOLID (RAY MINIMUM): 0.9210 mm, AT X=25.809
Y=35.500 Z=52.874 â€” MEASURED OVER THE WHOLE SOLID BY RAY+EXACT AT 0.3700 mm
SAMPLE SPACING (A FEATURE NARROWER THAN THAT CAN BE MISSED). THIS IS A
DISTANCE THROUGH MATERIAL, NOT A WALL: AT AN EDGE, A FILLET RUN-OUT OR A
CHAMFER TIP IT IS REAL AND UNPRINTABLE BY DEFINITION. DO NOT JUDGE
PRINTABILITY BY IT â€” THE NEXT NOTE IS THE ONE THAT DOES.
4. PRINTABLE MINIMUM WALL: 0.9236 mm, AT X=25.925 Y=35.375 Z=54.170 â€”
MEASURED AS THE SMALLEST MEDIAN WALL OVER A NEIGHBOURHOOD OF 1.1100 mm (>=
8 SAMPLES), RAYS CAPPED AT 4.000 mm, BY
cecad.inspect.printable_wall_detail. AGAINST THE 0.8000 mm FLOOR (2
PERIMETERS @ 0.4 mm NOZZLE, cecad/printed.py:801): VERDICT PASS
5. GENERAL TOLERANCE CANNOT DETERMINE â€” SEE PRINT / DFM NOTES UNLESS
STATED.
6. SECTION A-A AT X=-25.00: THINNEST MATERIAL IN THIS PLANE ONLY 0.93 mm,
AT Y=36.49, Z=55.15 â€” A SCAN OF ONE CUT, NOT THE PART MINIMUM.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

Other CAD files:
reviews/v0004/00 Open in your own software/Microduck - whole robot.3mf
reviews/v0005/00 Open in your own software/3MF 1 - whole robot assembled.3mf
reviews/v0005/00 Open in your own software/STEP 3 - real solid CAD parts only, assembled.stp
out/drawings/microduck-shin/microduck-shin.dxf
research/mesh-repair-2026-09-09/Microduck-Review-F/02 Look at the parts/01 Ankle Left/Drawings and details/microduck-ankle-left.dxf
research/mesh-repair-2026-09-09/Microduck-Review-F/02 Look at the parts/02 Ankle Right/Ankle Right.stl
research/mesh-repair-2026-09-09/Microduck-Review-F/02 Look at the parts/02 Ankle Right/Drawings and details/microduck-ankle-right.dxf
ce-parts/microduck-foot-left/iterations/v0.0.1/geometry/foot_left.stl
out/drawings/microduck-shin/detail-A-supplement-build/microduck-shin.dxf
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

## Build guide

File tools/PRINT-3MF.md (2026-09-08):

# Connected 3MF export

`compact_plate.py` now writes shared vertex indices with `indexed_3mf.mesh_xml`.
The prior STL-style export gave every triangle three fresh vertex indices.
OrcaSlicer 2.4.2 accepted that archive but omitted substantial model geometry.

Measured 2026-09-08 on the exact Microduck eye-ring surface, using the farm's
`partgate` with checks enabled, identical .4/.6 Standard H2D profiles and no brim:

| Input | Actual model layers | Slicer estimate |
|---|---|---|
| STL | 1–48 contiguous | 693 s / 2.6 g |
| Shared-index 3MF | 1–48 contiguous | 693 s / 2.6 g |
| Separate vertices per triangle 3MF | 41–46 only; body absent | 469 s / 0.2 g |

All three passed the old partgate, demonstrating why slicer exit status and
watertightness after coordinate welding cannot certify deposited geometry.
The two 3MF inputs differ only in vertex sharing. The experiment retained face
orientation and coordinates. See
`out/print/independent-codex-2026-09-08/experiments/vertex-sharing-controlled-test.png`
and its scripts/results.

The exporter welds coordinates at its serialized precision (four decimals),
including signed zero. It preserves triangle order and winding. This is a
connectivity fix, not automatic repair of self-intersections or zero-volume
components. Run `python3.12 tools/test_indexed_3mf.py` to check topology and
oriented geometry preservation. Use a Python with working XML support.

HEAD-V5 is immutable failed evidence. `HEAD-V6-candidate` changes only vertex
sharing and includes `reindex-proof.json`, asserting identical oriented triangles
for all 11 objects against the original unsliced HEAD-V5 input. Candidate status
does not authorize printing. Re-slice, verify model-only layer continuity and
mesh/toolpath correspondence, then satisfy the normal machine preflight and
physical bed-clearance requirements before any send.

The final offline candidate is `out/print/plates/HEAD-V7-candidate/`: it also
rotates the jaw +90 degrees around Y to resolve a measured layer-2 unsupported
expansion. Its `VALIDATION.md` names exact artifact hash, independent measurements,
remaining terminal-feature uncertainty and physical preflight requirements.
No candidate was sent by the validation agent.

HEAD-V9 supersedes V7 for the final manufacturing handoff. It also rotates the
neck bracket to eliminate its terminal thin-slice omission and removes only the
yaw's six-face zero-volume component, with an unchanged-main-body/A-B-slice proof.
`out/print/plates/HEAD-V9-candidate/VALIDATION.md` records the exact final SHA,
corrected partgate's retained diagnostic log and root's live-H2D PASS. Dimensional
fit/strength are explicitly separate from these print-layer checks.

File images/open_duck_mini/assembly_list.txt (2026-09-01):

9ed8591a-7c96-4410-8d7e-9b7d88c6bd1f Assemble_the_trunk
ae36b396-a34a-4691-8e62-fd916cd1f76c Assemble_the_trunk
d4a6ba6c-852f-440e-afb7-3b9ca66ad3dc Assemble_the_trunk
31c031b7-58b8-4c4c-a3fa-1f14a310c2f2 Assemble_the_trunk
6749a5ba-cea9-4b0a-ac32-f32e130fd057 Assemble_the_feet
1a77f2f8-56ea-43d2-91c7-78130456c45b Assemble_the_feet
197cd9b7-05a6-46ed-9af5-d2def37970c8 Assemble_the_feet
f532fbcc-100b-4715-96a8-66697e4fda26 Assemble_the_feet
71b9ad91-864e-423f-97a3-911d65182ab9 Assemble_the_feet
59e15c7c-3515-4408-bfe9-80e30c4cd007 Assemble_the_feet
41eb01a2-d6f9-43b1-a83e-d14785907425 Assemble_the_shins
a1432505-6b6c-4765-aea6-0a7a0b8b220b Assemble_the_shins
54615217-fec9-46dd-8b40-e21a4f527b55 Assemble_the_shins
951157a4-26dc-41bb-b97f-18dbbb0c1cd3 Assemble_the_thighs
368a85ad-1c58-4db2-bdd0-812334b6c784 Assemble_the_hips
768f1664-030c-4432-9071-c52d79d3ef6b Assemble_the_hips
e1287f67-320c-42cf-a5dc-84f4c64abb17 Assemble_the_hips
dba458ae-e9cb-4e16-a82e-cbe74d2350fa Assemble_the_hips
a7169791-9f0a-4827-aea7-00ab1d0f6212 Assemble_the_hips
4921b29b-b38b-423d-9da1-1c8f84689e84 Assemble_the_hips
f96fe44f-a7bc-423e-a925-4aef3e7bf568 Assemble_the_neck
a4dba395-eb0d-4150-8980-8e14f1173d02 Assemble_the_head_mechanism
4648cd6c-391e-41e4-9617-4ecebfa9215b Assemble_the_head_mechanism
03f3bdae-06c3-4c37-b68f-14587edd6123 Assemble_the_head_mechanism
04a219d8-bbaf-4910-b5d3-7ca67bce466c Assemble_the_head_mechanism
71545d40-f0f5-411d-a8d5-1cd676a74e75 Assemble_the_head_mechanism
8772996d-5906-48fa-8cbe-6b6823982375 Mount_the_IMU
172f44c7-c7c6-47f8-894a-14024abd24f4 Mount_the_IMU
d3376494-4690-4484-8352-132e6284731a Electronics
371db809-7cb3-47e1-b277-7fc2bdf21025 Battery_pack
3acfa4e6-ecf7-41f6-a965-35a3040f52fb Battery_pack
ef4cd513-6b8d-41fa-9cc3-149fc8333d3e Head
91284081-a563-4c02-bb3d-194b3afbc25c Head
96fd5347-bff7-47e9-a7bd-fde17ab1bcd2 Head
081d8840-8e88-4938-9d9a-4d97614e6261 Body
679a9cd2-89ca-41e8-9d03-f93fc040068b Body
ca292c48-1c72-4649-b7d1-4d3c9eac62ac Body
312ec747-8eb4-4145-92eb-c1c3ddba80da Body
864d9dd7-3daf-4e63-913c-2e99157e4aaf Body

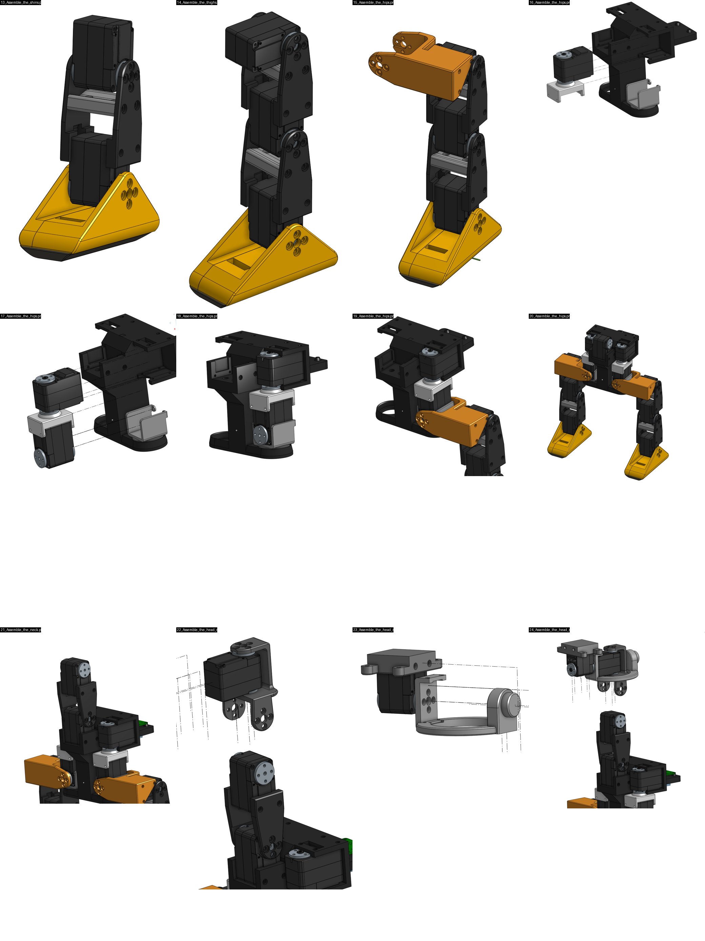
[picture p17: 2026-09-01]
research/mesh-repair-2026-09-09/Microduck-Review-F/07 Files for the engineer/Project files/images/sheets/odm_assembly_2.jpg

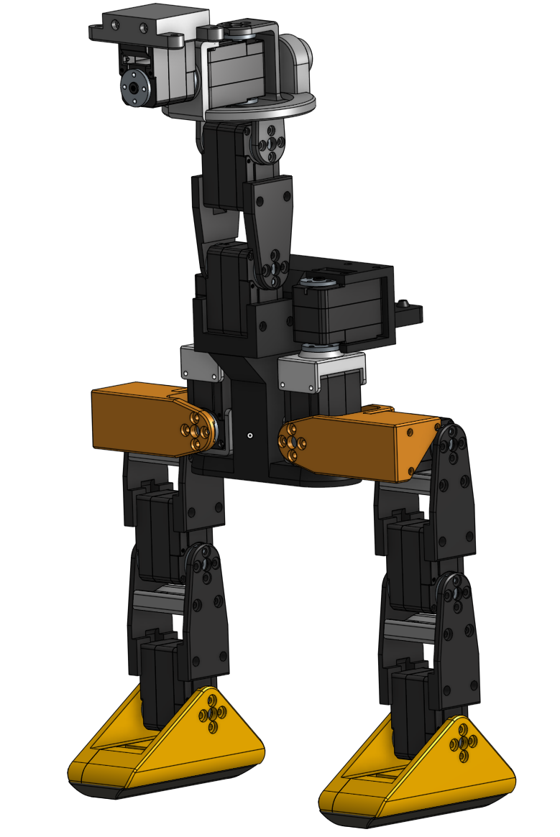
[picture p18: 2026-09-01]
research/mesh-repair-2026-09-09/Microduck-Review-F/07 Files for the engineer/Project files/images/open_duck_mini/assembly/26_Assemble_the_head_mechanism.png

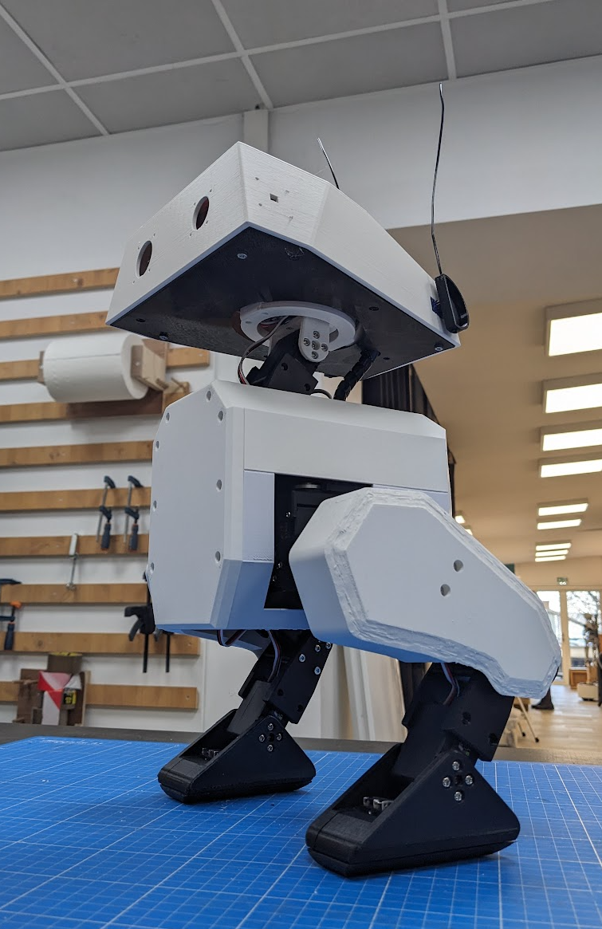
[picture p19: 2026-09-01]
research/mesh-repair-2026-09-09/Microduck-Review-F/07 Files for the engineer/Project files/images/open_duck_mini/assembly/38_Body.png

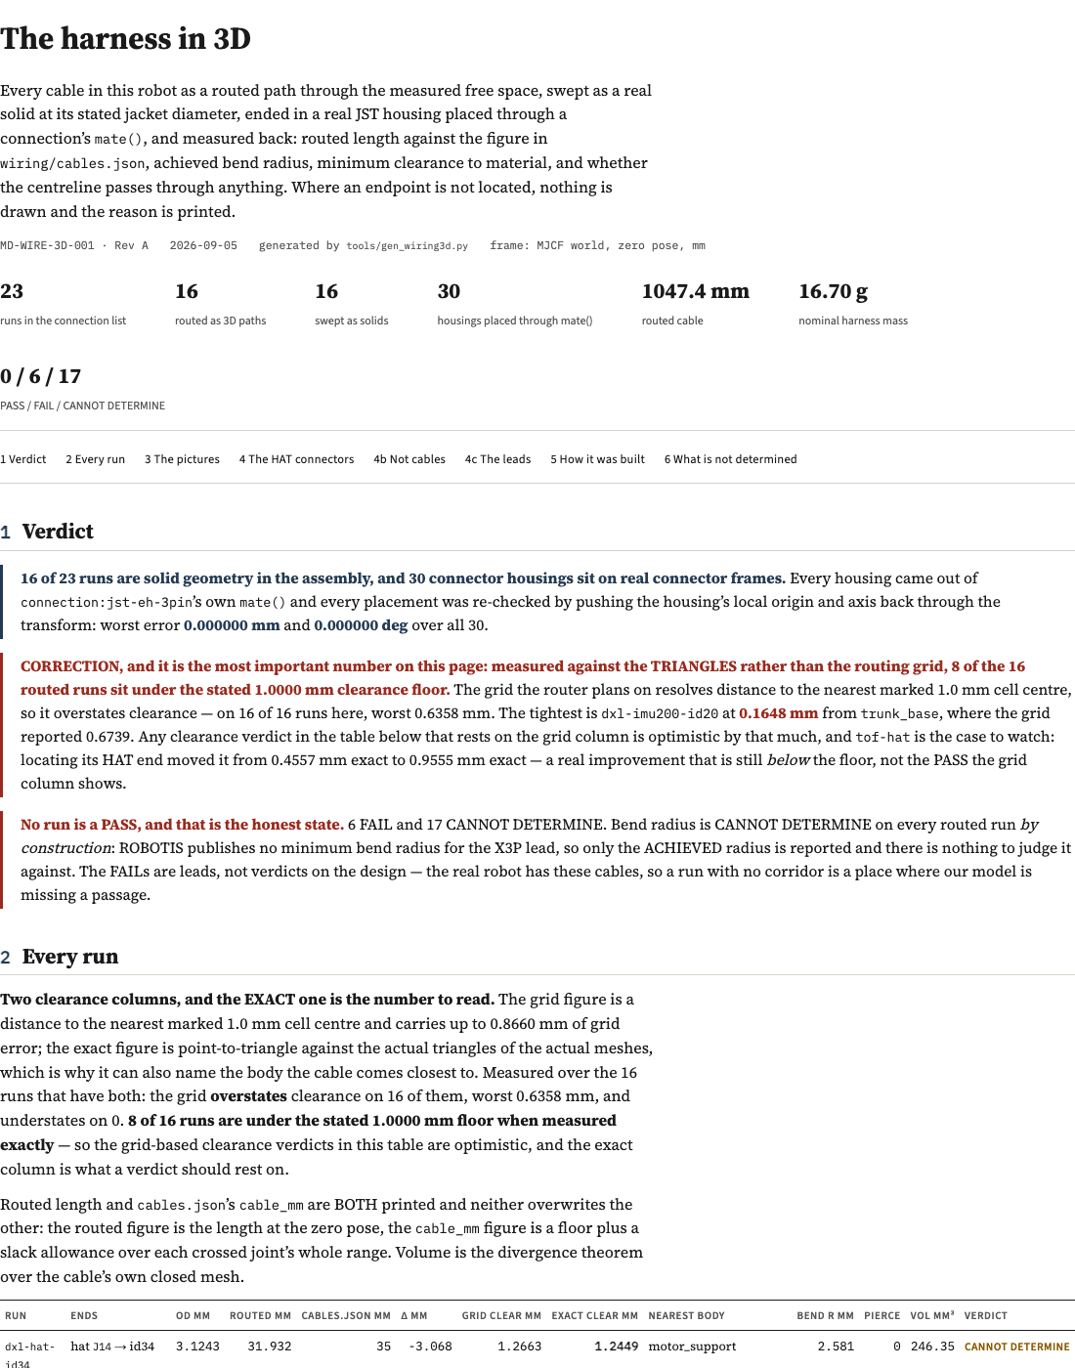
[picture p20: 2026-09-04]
WIRING-3D-01.png

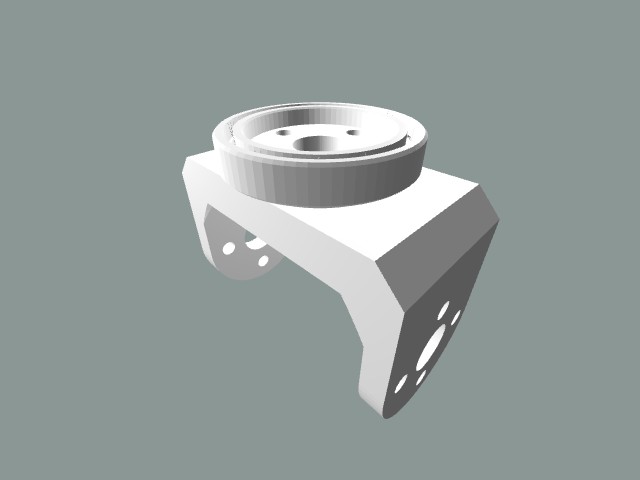
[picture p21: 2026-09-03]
reference/makerworld-3250889/page/images/08_颈俯仰.jpeg

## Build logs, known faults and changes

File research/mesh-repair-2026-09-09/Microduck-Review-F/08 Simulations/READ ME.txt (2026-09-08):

Open Mechanical simulation review.html to see the illustrated results.
This is a mechanical motion and contact study. The standing test fell; physical strength and cable movement are not validated.
Files for the engineer contains the exact simulation model and mesh assets.

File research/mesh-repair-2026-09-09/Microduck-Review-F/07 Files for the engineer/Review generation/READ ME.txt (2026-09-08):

Reproduction tools from ce-cad and Microduck.
Build the source snapshot with python3 -m cecad.reviewpack --project ROOT --mesh ASSEMBLY.json --out NEW_DIR.
The project prepare_review_geometry.py selects the existing yaw-roll repair for this dated review; it preserves source print files and records the repair provenance. It requires NumPy and SciPy.
Browser evidence scripts use ce-cad web/_cdp.mjs and installed Chrome. Run the viewer test before embedding images, then the document test to verify all embedded images offline and produce the PDF.
The purchased-component gallery is populated by add_bought_model_parts and illustrate_bought. Image embedding is a one-time generation step.
Seal only after inspection using python3 -m cecad.reviewpack --out DIRECTORY --seal.
Archived source documentation is historical and may refer to earlier revisions or online services; START HERE.html is the measured offline entry point.

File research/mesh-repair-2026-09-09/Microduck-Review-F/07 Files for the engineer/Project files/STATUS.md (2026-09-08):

# STATUS — 2026-09-02, 03:15 (written while the account's session limit blocks agents until 6:50am; a cron resumes everything at 6:53)

**Historical snapshot.** Read the [2026-09-08 recreation/sourcing continuation](docs/RECREATION-2026-09-08.md)
before using this page for present readiness or task ownership.

Against GOAL.md's rungs. Nothing below is claimed without its artifact.

| rung | verdict | proof |
|---|---|---|
| 1 · every part on the shelf | **DONE BY DECISION** (2026-09-02, Leif: 'use it directly') — Pollen's meshes are the primary geometry for every part; 20 parametric rebuilds PASS and replace their slugs; the remaining organic shells stay mesh-backed on purpose. Previously: **PARTIAL** — 54 slugs; **15 parametric rebuilds PASS** vs Pollen's meshes (worst p95 1.00 mm — shin; best 0.001 — trunk-base; ankles 0.012, hip-bracket 0.162/0.242, thighs 0.20, feet/neck done in round 2), ~30 mesh-backed vendor parts build as loaders; head shells, face, jaw group + connection folders still queued (limit killed them twice) | `tools/watch-pass.log`, `out/refcheck/*/`, per-folder `evidence/` |
| 2 · assembly builds in kernel | **PASS** (with named fallbacks) — 70/70 placements, 144 × 150 × 264 mm measured | `out/render/assembly-now.png`, `bin/cad assembly:microduck` |
| 3 · animated, open-source sim | **PASS, independently verified** — MuJoCo 3.12 + Pollen's ONNX policies, 9 rebuilt meshes swapped in; walk 0.79 m/8 s no fall, identical trajectory vs stock; vx sweep shows 0.15 m/s is inside the policy's stand-still band (0.25 used) | `out/sim/walk.mp4`, `walk.gif`, `sitstand.mp4`, `stand.mp4`, `out/sim/report.md` |
| 4 · electronics | **PARTIAL** — XL330-M288-T + LSM6DSV16X datasheeted verbatim with provenance (tamper-checked); netlist lane done in wiring's model; **Robot HAT PCB + electronics verify still queued** | `ce-parts/xl330-m288-t/`, `ce-parts/lsm6dsv16x/`, `docs/ELECTRONICS-AND-SOFTWARE.md` |
| 5 · wiring | **PASS, independently verified** — 22 cables, 1615 mm, chain order from the MJCF tree, bus drop PASS at both pack extremes, the battery feed crossing 720° of head joints named as THE routing problem | `wiring/`, `wiring/CABLES.md`, `wiring/drop.json` |
| 6 · manufacturing | **PARTIAL** — 10/10 drawings verified (autosheet + verify_sheet), all 30 printed parts sliced with REAL slicer numbers (PLA 218.29 g / 9.93 h, TPU 26.20 g / 2.41 h, Bambu H2S presets named), 2 plate 3MFs, 7-step manual, bom.csv; **bin/deliver package + verify still queued** | `out/drawings/INDEX.md`, `out/print/PRINT.md`, `ce-assemblies/microduck/current/manual/MANUAL.md` |
| 7 · production research | **PASS** — cost at 1/10/100/1000 with 155 sources; the finding: 15 × XL330 = $358.50 is 75 % of read bought cost ($472–481/robot), already over Pollen's $399 retail → the volume question is one ROBOTIS OEM quote; battery shipping (UN3481 PI967 II), CE/FCC, assembly labour 36–101 min | `docs/PRODUCTION.md`, `docs/production/*.md` |
| 8 · this file | written 03:15, updated by the 6:53 cron | |

## Defects the independent verifiers found (open, honest)
- ~~trunk-base part.py hip_yaw connector names mirrored vs interfaces.json~~ **fixed 03:10** (names swapped; geometry was symmetric, join()-by-name was the hazard).
- banana-pcb-locker docs cite right_shell's placement instead of its own (component.json / part.py / interfaces.json) — docs-only, geometry PASS.
- hip-bracket's first builder produced a 16 mm disc; a later round PASSed refcheck 0.162/0.242 at 02:58 — the cron confirms which builder is current.
- power-support upper-flange mate and several sub-0.3 mm drafts: CANNOT DETERMINE (decimation floor).

## What blocked, twice
Anthropic session limits (00:30–01:50, 03:05–06:50) killed every running agent; all workflows are resumable from cache and a one-shot cron at 6:53 resumes them. Everything completed before each cut is committed and pushed.

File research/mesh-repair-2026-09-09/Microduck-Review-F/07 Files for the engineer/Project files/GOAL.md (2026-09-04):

# GOAL — Microduck, night of 2026-09-02 (Leif: "write a good goal … i will give to a claude instance to work on this all night")

Leif, 2026-09-02, verbatim on top of this goal: *"use opus 5 for workflows youre the orcehstrator which use fable 5.1 but to save tokens use opus 5 for workflows."* and *"be token efficent and use opus for as much as possible"*

```
GOAL — Microduck: drive to a physically manufacturable product, verified end to end.

REPO: /Users/leifrydenfalk/dev/ce-workshop/ce-designs/microduck  (own git repo + triad root)
WORKSHOP: /Users/leifrydenfalk/dev/ce-workshop  (read its CLAUDE.md + TRIAD.md first)
RUN CAD/SIM AS: ce-cad/bin/cad <script.py>   (FreeCAD python 3.11; system python3 has no numpy/PIL)
export CE_TRIAD_ROOT="$REPO:$WORKSHOP"

YOU RUN THIS PROJECT. Do not stop to ask permission. Do not hand work back. If something is
undetermined, that is YOUR work item — resolve it by measuring, reading, or researching.
Escalate to the human ONLY for a genuine product preference or spending money.

HOUSE RULES (non-negotiable)
- MEASURE, never assert. Every number carries a source: a file:line, a datasheet page, a
  distributor URL, or a measurement you just took.
- Three verdicts: PASS / FAIL / CANNOT DETERMINE. A missing value stays missing — never a
  plausible default. Never loosen a check to make it pass.
- Full engineering precision. Do not round to 1-2 dp. Dimensions in mm to 3-4 dp, and state
  the tolerance basis. Units mm / g / degrees / volts.
- LOOK at every artifact you produce (render it, screenshot it, Read the image back). A file
  that exists is not a file that is correct.
- Everything is a document in the repo. HTML, not Markdown, in the shared academic style
  (link tools/doc.css). Regenerate documents from data with a script in tools/ — never
  hand-maintain a table that a generator could own.

WORKFLOWS: use them aggressively for every lane. Pass {model: 'opus'} on every agent() call.
Spend tokens freely. Prefer pipeline() over barriers. Adversarially verify findings.

STATE AS OF HANDOFF
- COMPARISON.html — our CAD beside real product photos at 8 matched camera angles + measured
  dimension table for all 47 meshes. 9 parametric rebuilds, 9/9 dimensional PASS, worst-axis
  deviation 0.7193 mm. Generated by tools/gen_comparison.py from out/verify/mech_dims.json.
- Renders: sim/compare_render.py (MuJoCo studio) and sim/assembly_steps_mj.py (assembly steps).
- Stress FEA (out/stress/report.json): shin SF 7.51, ankle SF 2.02, hip-bracket SF 6.42 PASS
  at 20 N design load. upper-leg = CANNOT DETERMINE (connector-name bug in
  sim/stress_evidence.py) — FIX IT.
- Electronics/sourcing workflow may still be running or have landed; check /workflows and
  the transcript dir before re-running.
- RELEASE.html is the master dossier. It must end up containing everything.

CRITICAL OPEN FINDINGS (from COMPARISON.html §5) — close these
1. SIM HEAD ≠ PRODUCT HEAD. top_head_shell is 91.751 x 122.688 x 46.339 mm, far longer
   front-to-back than the compact domed head in every product photo, and the eye bezel is
   missing. Tooling cut from this mesh is WRONG. Re-model the head from the product
   photographs (photogrammetry / silhouette fitting against images/store/*), grade it, and
   replace it. This is the single biggest geometric blocker.
2. Battery mesh is np_f970 (38.600 x 20.600 x 70.800 mm) but docs say NP-F550 class.
   Determine the real cell, then re-check the power_support cavity against it.
3. Compute placeholder mesh is a Pi Zero 2 W; documented host is Radxa Zero 3W. Same
   65 x 30 mm envelope, different connectors/mounting. Verify against the real board.
4. Two ankle revisions ship (ankle_left Y=36.500 vs ankle_l_v1 Y=46.500). Determine which
   is current.
5. Drawing generator has two measured defects: it merges coaxial holes into a phantom
   counterbore, and the wall-thickness note reports a section scan rather than the true
   minimum. Fix the generator, then regenerate every sheet.
6. Three custom PCBs (Robot HAT, imu_to_dxl, banana contact board) have no published design.
   They must be schematic-captured, laid out, and quoted before anything is fabricable.

LANES TO COMPLETE (workflow each; produce a document for each)
A. HEAD RECONSTRUCTION — close finding 1. Deliver a graded head model + before/after
   photo-match evidence.
B. MECHANICAL DRAWINGS — fix the generator, regenerate all sheets with ISO views from every
   angle, full dimensions including radii, hole tables, sections, tolerances, surface finish,
   and a reference photo on each sheet. Deliver out/drawings/INDEX.html.
C. ELECTRONICS VERIFICATION — every component: exact MPN, package, physical dimensions,
   pinout, voltage, current draw, mass. Every value cited. Deliver ELECTRONICS-DATASHEET.html.
D. CUSTOM PCB DESIGN — schematic + layout + Gerbers + BOM for the three boards, or a
   fully-specified statement of work with real fab quotes if design is out of scope.
   Deliver electronics/robot-hat/, and a PCB-PACKAGE.html.
E. SOURCING & RFQ — every bought line: >=2 real distributors, unit price at 1/100/1000, MOQ,
   lead time, alternates. Deliver SOURCING.html and a ready-to-send RFQ.html the human can
   email to suppliers. DO NOT contact anyone yourself.
F. SIMULATION EVIDENCE — run far more: FEA on every structural part (fix the upper-leg case),
   drop/impact, fatigue on the ankle (lowest SF at 2.02), thermal on the servos and the
   compute, battery runtime, gait robustness sweeps, and tolerance stack-up on every joint.
   Deliver SIMULATION.html with every run's inputs, outputs and verdict.
G. MANUFACTURING PLAYBOOK — the document the team executes: process selection per part
   (print vs mould) with break-even quantities, DFM review of every part, print profiles,
   assembly line steps with jigs and torque specs, QA test plan with pass/fail gates,
   packaging. Deliver MANUFACTURING-PLAYBOOK.html.
H. TEST & VALIDATION PLAN — how we prove a built unit works: electrical bring-up, servo ID
   and calibration, sensor checks, walk acceptance test. Deliver TEST-PLAN.html.
I. TOOLING (ce-workshop, not just ce-cad) — every capability you needed and had to hand-roll
   becomes a real tool in the appropriate repo, with docs. Make this whole loop easy to repeat
   for the next product.

FINAL INTEGRATION
RELEASE.html must link and summarise every document above, carry the honest readiness matrix
with what still blocks factory, and open cleanly. Screenshot it and Read it back before you
call it done. Commit continuously with clear messages. Record entries in ce-changelog.

DEFINITION OF DONE
A competent shop could take this repo and build a working Microduck: every part has a
dimensioned drawing or a print file, every bought item has a supplier and a price, every
custom board has a design or a quoted SOW, the assembly and test procedures are written, and
every claim in the repo is either measured, cited, or explicitly marked CANNOT DETERMINE.
```

## HANDOVER CORRECTIONS — read before acting on the findings above (added 2026-09-02 21:25 by the orchestrator, from the previous session's handover)

1. **Finding 1 (head) is CANNOT DETERMINE, not confirmed.** `tools/head_analysis.py` → `out/verify/head_analysis.json` measured scale-free silhouette ratios: head length / robot height agrees to 3.76 % (product 0.4233, ours 0.4392) — the head is NOT markedly longer. The aspect ratio differs +69 % (1.206 vs 2.042) but the reference photo has the beak OPEN and the head TILTED, which inflates apparent head height. Verdict CANNOT DETERMINE (commit 960943a, COMPARISON.html §5). **Lane A must first SETTLE it**: photogrammetric scaling against the XL330-M288-T visible in the same frame (body face 20.000 × 34.000 mm, ROBOTIS drawing cited), then measure the head shell in mm against the mesh's 91.751 × 122.688 × 46.339 mm, posing jaw_soft open to match the photo (the jaw is NOT an actuated joint in the published model). Re-model the head ONLY if the measured deviation exceeds the 1.0 mm p95 / 1.5 mm bbox rule of docs/REBUILD-PROTOCOL.md; otherwise the deliverable is the measurement and the eye-bezel question.
2. **Electronics component verification already ran** (previous session, 14 Opus agents, each component: MPN, package, dims, pinout, voltage, ≥2 distributors with price at 1/100/1000, MOQ, lead time, cited). Results: `out/verify/electronics_verify.json` (canonical, commit 1fe090a; `out/handover/elec-verify-wf_969f3a4c.json` is the same journal copied earlier). Its five design-changing findings are in `workflows/RUNNING.md`. Lanes C, D, E and every verify/fix stage: CONSUME it (merge into electronics/elec-spec.json and spec/sourcing.json, re-check citations), do not redo it.
3. **A manufacturing workflow (DFM / process / assembly+jigs / QA / sourcing ×3 / synth) died with the previous session and was RELAUNCHED by the orchestrator from `workflows/manufacturing.js` (5 DFM groups + process + assembly + QA + 3 sourcing + synth, Opus). Its results land in `out/handover/manufacturing.json` when it returns. Lane G and its fix stage: check that file and merge rather than duplicate.
4. **Detached FEA is running**: `sim/stress_matrix.py` → `out/stress/matrix.json` + `matrix.log` (buffered; read the file). 4 structural parts × 3 load cases (standing 20 N / landing 60 N / lateral 15 N) in PLA with a gmsh mesh-size fallback [None, 2.0, 1.5, 1.2, 1.0, 0.8], then mesh convergence on the governing case, then a material sweep PLA/PETG/ABS/NYLON/ASA. The upper-leg gmsh failure is a MESHER SIZE issue — the solid is valid, closed, 462 faces. Lane F: consume matrix.json, do not restart it, do not run a second copy.
5. **Unit trap**: Pollen's reference assets are in METRES (×1000); our rebuilds are native mm. `sim/mech_dims.py` handles it. Do not repeat that mistake.
6. **Renders**: `sim/compare_render.py` (MuJoCo studio; camera front=az180, profile-left=az270, profile-right=az90, ¾ front-left=az225, ¾ back-right=az45; joint zooms need distance ≥ 0.16 m or the near plane clips to a blank white frame). `sim/assembly_steps_mj.py` for cumulative assembly frames. Every render of ours sits beside the real photo (Leif's rule).
7. `INDEX.html` (tools/gen_index.py) is the repo front door; it stats every entry before writing. Regenerate it after adding a document.
8. **LANE OWNERSHIP (Leif, 2026-09-02: "be highly parallel. use fable 5.1 for difficult tasks").** Read `out/handover/LANE-OWNERSHIP.json` before starting. If your lane letter is listed under `owned_elsewhere` and you are an agent of workflow wf_b277547c-936, do NOT do the work: return immediately as that file instructs. Lanes A, F, H run in a parallel workflow.

## STANDING ORDERS ADDED 2026-09-03 — Leif, verbatim. These bind every agent and every workflow.

> lots of details like joints and screws and bolts are mising from our cad
> everything muyst be there. all everything including ball joints and it must
> match exactly this is your job and the job of your agents tell them they have
> more freedom to explore and create their own tools and whatever they need this
> is their machine

> make more detailed everything tell agents and workflows to do this divide the
> work prioperly were making this for real a lot more detail and attention to
> details.

> the wiring should b e in our cad designs add it proeprly do even more details
> and poses and even more detailed joint pictures and comparrisons

**What this means in practice, and it is not negotiable:**

1. **EVERY PHYSICAL THING IS IN THE CAD.** Screws, nuts, heat-set inserts,
   washers, ball joints/ball studs, bearings, cables, connectors, adhesive
   joints, the lot. MEASURED 2026-09-03: `ce-assemblies/microduck/current/bom.json`
   holds **38 rows and ZERO fastener rows** — because the assembly was seeded
   from Pollen's MJCF, which carries only visual and collision geometry. Yet
   `SPEC.md:75-76` reads the robot as an **M2 system: Ø2.2000 clearance ×77,
   Ø4.4000 counterbore ×28, Ø1.6000 tap ×20, Ø2.7000/2.8000 ×20**. Those 145
   holes each imply a fastener that is not in our model. Find every one by
   MEASURING the geometry, put it in the assembly through a connection (never a
   literal transform), and let the BOM and the drawings carry it.
2. **IT MUST MATCH EXACTLY.** Where our model and the reference disagree, the
   disagreement is measured and reported, never smoothed. A part nobody measured
   is CANNOT DETERMINE with what settles it.
3. **THE AGENTS OWN THIS MACHINE.** Leif: *"they have more freedom to explore and
   create their own tools and whatever they need this is their machine"*. So:
   write the tool you wish existed rather than working around its absence
   (PROTOCOLS.md P11 — a capability a core app lacks is part of your task, and a
   one-off script that dies with the session is the defect). Promote anything
   reusable into `ce-cad`, `ce-struct`, `ce-wire` or `bin/` with its docs and its
   self-test. Explore: read the reference, take a measurement nobody asked for,
   follow the thing that looks wrong.
4. **DIVIDE THE WORK PROPERLY.** Every lane states what it OWNS (paths) before it
   starts; two agents never write one file; a lane too big for one agent is split
   by artifact, not by adjective.
5. **MORE DETAIL, EVERYWHERE.** More poses, more joint pictures, more sections,
   more comparisons against the real photographs, more dimensions on every sheet.
   Depth is the deliverable.

## STANDING ORDERS ADDED 2026-09-03 LATE — Leif, verbatim. Four more, all binding.

> Give the microduck these researches to injest and utilize and do research on:
> https://makerworld.com/en/models/3250889-microduck-robotic-duck-structural-parts-simulation
> https://github.com/pollen-robotics/microduck_rl/tree/develop/src/mjlab_microduck/robot/microduck/assets
> and an new image covering the components of the microduck internals. the cad
> and 3d printable files and stuff should be in these resourches tell it to dive
> deeply into it

> We have a Chinese guy working on this project and we will work together with
> all the resources and manufacturing and factories and research on this. We
> have a factory and 10 engineers to put on this. So just send the documents of
> what needs to be done. Give it this verbatim.

> it should not run simiulation just once it should iterate and simulate,
> design, fix, simulate, design, fix, simulate, design fix until it matches
> exactly the real airtag based on all the research all night never stop it
> should set its own goal so it never stops. we need this to be a real product.
> same as with the microduck two real world products and real world results.

> I like the halo dock browser more but the styling of themicroduck more with
> the white. redesign the microduck repository / document browser to have this
> same clean sideview i like it a lot. tell the workflows working on this

**What binds every agent from here:**

1. **THE AUDIENCE IS NOW A FACTORY AND TEN ENGINEERS.** Not us. A stranger who
   watched no measurement being taken must be able to build from the paper. Say
   per artifact whether it is READY TO BUILD FROM or NOT YET, and put what is
   not ready at the FRONT, not the back.
2. **CONVERGE, DO NOT DELIVER ONCE.** "matches exactly" is a MEASURED SCALAR
   THAT SHRINKS. Every iteration picks the largest delta, changes the design,
   re-runs the tool that measures it, and records the number before and after.
   An iteration that makes something worse is a finding: record it and revert.
   Never loosen a check to make a delta look smaller. The convergence table
   (`CONVERGENCE.html`, generated from data) is the project's scoreboard.
   Measured deltas open as of 2026-09-03 23:xx: **28 drawing sheets 0 PASS /
   28 FAIL** on our own `bin/sheetcheck`; **bom.json 38 rows, ZERO fasteners**
   against a 145-hole M2 census; **139 CANNOT DETERMINE items** open; the head
   shell front-to-back geometry vs the product photographs.
3. **NEVER STOP; SET THE NEXT GOAL YOURSELF.** When a lane lands, start the
   next on the largest remaining delta without being asked.
4. **DIVE DEEPLY INTO NEW SOURCES.** Archive the primary page into the repo,
   pin the commit SHA for anything from a git branch, record the licence and
   attribution, and diff new geometry mesh-by-mesh against `reference/`.

## THE STANDING ORDER — Leif, 2026-09-04, verbatim. This is the finish line.

> continue with everything when the limits reset. try to be more token efficent.
> continue with the work until youre 100% done and we have production ready
> airtag clone and production ready microduck clone. open all of hte results for
> me to look through and commit and push everything as you go with documents
> detailing what we need to do.

**100 % DONE means the convergence scoreboard has no open red row:** every
drawing sheet at 100 % dimension coverage against A4, the fastener census
reconciled into the assembly, the head settled against the photographs, and all
139 CANNOT DETERMINE items either closed or explicitly deferred to a named
physical measurement on a real sample. Nothing else counts as done.

**COMMIT AND PUSH AS YOU GO.** `tools/commit-lane.sh` then `git push origin main`
after each meaningful commit — not at the end. Three interruptions on 2026-09-03
destroyed unsaved work; only pushed work is safe.

**KEEP THE "WHAT WE NEED TO DO" DOCUMENTS CURRENT.** FACTORY-PACK.html,
WORK-BREAKDOWN.html and FACTORY-QUESTIONS.html are living documents: any lane
result that closes or opens a work item updates them in the same commit. A stale
work breakdown is worse than none.

**LEIF LOOKS AT RESULTS IN THE BROWSER** — `tools/docs_server.py` on
http://localhost:8842. Anything you produce must be reachable and readable there.

**EVERY AGENT RUNS ON OPUS 5 — SUPERSEDES THE EARLIER FABLE NOTE.** Leif,
2026-09-04, verbatim: *"all workflows and eveyrhing must use opus 5 this is
highest priority change because fable 5.1 consumes like a monster"* and *"Do
this first. first thing you do is this change to change verything to use opus
5"*. Subagents DO NOT inherit the parent's model — an `agent()` or Agent call
with no `model` falls back to the harness default, which is Fable. So every
`agent()` call in every workflow script and every Agent tool call passes
`{model: 'opus'}` explicitly. Measured 2026-09-04 across 50 live agent
transcripts: 797 turns on Fable vs 472 on Opus, despite both orchestrator
sessions running Opus. Any earlier note in this file about running lanes on
Fable is void.

**BE TOKEN EFFICIENT.** Do not re-read what is already known, do not re-derive a
settled fact, keep prompts tight. Depth of measurement, not depth of prose.

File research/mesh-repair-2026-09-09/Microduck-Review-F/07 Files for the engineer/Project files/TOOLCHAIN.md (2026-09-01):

# TOOLCHAIN — what this repo needs to reproduce every file in it

*Leif, 2026-09-01: "add all screenshots and everything to the git repo this
should be everything anyone needs to reproduce this design."* This repo holds
the DESIGN and its evidence. The TOOLS that build and grade it are ce-cad,
which is proprietary (Leif Rydenfalk, all rights reserved) and lives in the
ce-workshop monorepo — deliberately NOT vendored here. What is pinned:

| component | version | where |
|---|---|---|
| ce-workshop (ce-cad + bin/triad) | commit `65042d5` or later on `main` (github.com/Leif-Rydenfalk/ce-workshop, private) | `~/dev/ce-workshop` |
| FreeCAD (the geometry kernel ce-cad drives) | 1.1.3, `/Applications/FreeCAD.app` (its bundled python has numpy 1.26.4 + matplotlib 3.10.8) | `bin/cad --doctor` |
| python for kernel-free tools | FreeCAD's `Contents/Resources/bin/python` (system python3 3.14 has no numpy) | |
| ce-cad modules written for this project | `cecad/mjcf.py`, `meshview.py`, `meshcompare.py`, `meshfeatures.py`, `meshslice.py`, `mjcfseed.py`; `bin/cad-mjcf`, `bin/cad-refcheck`; `Part.ellipsoid/loft/shell/scale/from_mesh` | ce-workshop `a9cca94`..`65042d5` |
| reference data | Pollen's MJCF + meshes, copied into `reference/` with SOURCE-COMMIT.txt | this repo |

Environment for every command in this repo:

```bash
export CE_TRIAD_ROOT="$HOME/dev/ce-workshop/ce-designs/microduck:$HOME/dev/ce-workshop"
```

`tools/` holds only scripts that belong to THIS design (the PASS watcher, the
whole-duck render); anything reusable is promoted into ce-cad and cited above.

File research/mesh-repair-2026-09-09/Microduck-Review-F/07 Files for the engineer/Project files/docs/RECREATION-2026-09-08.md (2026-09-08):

# Microduck 1:1 recreation — evidence and sourcing, 2026-09-08

The target is the original robot's geometry, fitted hardware, wiring and behavior.
The repository does not yet prove that target. A supplier PASS in
[`spec/sourcing.json`](../spec/sourcing.json) establishes its sourcing rule, not
that the offered part is the one Pollen fits. Keep replacement candidates
separate from confirmed original identities.

The latest [servo geometry audit](../research/xl330-geometry-revision-2026-09-08/README.md)
found a 6 mm modeled horn/idler pilot where ROBOTIS specifies 3 mm maximum
and M2 tapping screws. A corrected research candidate passes 100 finished-solid
probes; the published shelf iteration remains unchanged pending integration.
35 of 52 nominal servo-face screw penetrations exceed that limit in the existing
placement model. This is not a physical measurement or a replacement screw list.
The current run generator now withdraws all 52 servo ISO-length proposals.
The 64-screw assembly remains a historical nominal placement; a rebuild refuses
to silently remove withdrawn hardware. Twelve other generic nominal proposals
remain, also without original physical thread acceptance. The
[application check](../research/servo-fastener-restriction-2026-09-08/current-application.json)
records the corrected run data and unchanged assembly hashes.
The [revision dependency audit](../research/xl330-interface-revision-review-2026-09-08/REPORT.html)
also finds automatic ISO screw additions in the horn connection. A coordinated
major part/connection revision must reverify 66 direct endpoints and inspect
18 declared acceptors. Vendor solid sampling confirms center recesses absent
from the simplified candidate; its 100 passing mounting-hole probes do not
establish a complete external reproduction.

## Electronics: correction that changes the next task

Pollen publishes [the Robot HAT project](https://github.com/pollen-robotics/elec_RPI_Robot_HAT)
and [its KiCad libraries](https://github.com/pollen-robotics/lib_KiCAD).
The upstream API returned revision `23eab11927f95ceca0dfa35bf182caeb7db39ea0`
on 2026-09-08, the same revision cited by our September 3 identity lane.
The statement that every HAT schematic is unpublished is obsolete.

That lane's geometry report is also wrong. Reading the pinned PCB source gives
an outline coordinate span of **65.000034 × 30.900064 mm**, a declared thickness
of **1 mm**, and **four 2.7 mm drilled pads** inside the J4 footprint on a
**58 × 23 mm** pattern. Its reported 65 × 48.5 mm and absence of mounting holes
must not guide a redesign. These are file measurements, not a physical fit test.

Reproduce: `python3 tools/audit_official_hat.py`. The
[saved report](../research/official-hat-audit-2026-09-08.json) includes source URL,
SHA-256, exact outline blocks, drill counts and local hole coordinates. It checks
the expected eight outline primitives and four mounting holes and refuses a
different structure. No kernel, PCB editor or hardware is invoked.

The Microduck reference mesh was previously measured as 65.025 × 30.025 × 0.840 mm
in [`out/open/identity-sourcing.json`, ID-03](../out/open/identity-sourcing.json).
Thus the public board is much closer than the old report implied, but its roughly
0.875 mm larger short dimension and different thickness still need comparison
against the actual head and connector clearances. Neither the mesh nor the
family resemblance establishes the production revision. Obtain the board's
silkscreen/assembly number and both-side photographs from an original unit.

The existing archived official BOM supplies useful component identities:
TLV320AIC3104IRHBR codec (C181753), PAM8406D amplifier (C86270),
LMA2718T421-OA5-2 MEMS microphone (C7587901), BMI088, AP63205 regulator,
XC6206P182 1.8 V regulator, and LM5050-1. These are **public HAT family** facts;
confirm suffixes, DNP entries and the production revision before kitting.
[Archived BOM](../out/open/identity-evidence/hat/ASE01187-C1_elec_RPI_Robot_HAT_BOM.csv).

The September 8 electrical rerun after correcting I2S/MCLK and public HAT rails produced **82 PASS /
15 FAIL / 26 CANNOT DETERMINE** in [`electronics/report.json`](../electronics/report.json).
GPIO header pin 13 is not codec MCLK: the public HAT uses local oscillator Y1.
The provider is now modeled explicitly, with unresolved timing/installed-variant
evidence still reported as CANNOT DETERMINE. The public +3V3 and U3-derived +1V8 topology is now represented; board-level
current capacity and operating behavior remain unresolved. The servo voltage
conflict is material: catalog XL330 input is 3.7–6.0 V whereas the modeled runtime
bus is 6.6–8.2 V. Confirm the actual servo variant and rail; software error masking
does not establish hardware suitability. [ROBOTIS specification](https://emanual.robotis.com/docs/en/dxl/x/xl330-m288/).

## Where to source components

Vendor observations below were checked on 2026-09-08 by the Codex sourcing agent.
Prices retain vendor currency and exclude unverified shipping, tax and import
costs. Delivery country is still pending. No orders or supplier messages were sent.

| Need | Source and observed offer | Remaining 1:1 question |
|---|---|---|
| 15 servos | [ROBOTIS XL330-M288-T, 902-0163-000](https://en.robotis.com/shop_en/item.php?it_id=902-0163-000), USD 23.90 each; USD 358.50 for 15 | Confirm original M288/M077 ratio, voltage variant and firmware. Firmware ≥53 changes indirect-address/data tables; check runtime register assumptions. |
| Bus leads and servo screws | Same retail package includes one 180 mm X3P lead, six M2×6 TAP and ten M2×8 TAP screws per servo | For the existing 16-lead plan, 15 packaged servos leave one additional lead before spares. Buying only ten-packs would still require one extra pack. Reconcile lengths and slack. Included TAP screws are not automatically replacements for the assembly's metric screws/inserts. |
| Radxa ZERO 3W | [ALLNET China](https://shop.allnetchina.cn/products/copy-of-radxa-zero-3w): 1GB/8GB/header USD 23 sold out; 4GB/32GB/header USD 51 sold out; 2GB/no-eMMC/header USD 55.99 displayed Add to cart | [Radxa product brief §7](https://dl.radxa.com/zero3/docs/hw/3w/radxa_zero_3w_product_brief.pdf) omits 1GB/32GB. This means absent from the published catalog, not proof an OEM configuration does not exist. Listed alternatives change the specification. |
| IMX219 camera candidate | [Seeed 102110719](https://www.seeedstudio.com/IMX-219-CMOS-camera-module-M12-and-CS-camera-available-p-5372.html): USD 15.90; USD 12.50 at 10+; in stock | Exact board, lens, FOV and ribbon are unresolved. Sensor compatibility alone does not prove a match. UCTRONICS B0183's old offer was not successfully reverified. |
| HAT codec | [LCSC C181753](https://www.lcsc.com/product-detail/Audio-OpAmps_TI_TLV320AIC3104IRHBR_TLV320AIC3104IRHBR_C181753.html) | Manufacturer code maps to the official family BOM; no current price/quantity imported from search snippets. |
| HAT MEMS microphone | [JLCPCB C7587901](https://jlcpcb.com/partdetail/Linkmems-LMA2718T421_OA52/C7587901) | Listing matches the official family BOM. Confirm stock, assembly availability and the fitted board revision. |
| PCB fabrication/assembly | [JLCPCB process capabilities](https://jlcpcb.com/capabilities/Capabilities%2C/) and [assembly capabilities](https://jlcpcb.com/capabilities/pcb-assembly-capabilities) | Candidate fab route; quote the selected exact revision with stackup, BOM/DNP and placement files. An advertised starting price is not this robot's PCB quote. |

Existing sourcing records already cover bearings (MR1622 and 6700 family), JST
connectors, fasteners, battery packs and soft materials. Their September 2–3
offers remain historical, not refreshed stock. Do not buy the unknown original
battery, lens, NFC, speaker or LED solely because a candidate has supplier PASS.
The later ID-02 record reports support for both ToF generations; identify the
reference unit's generation instead of assuming every duck uses L8CX.

## Work parcels for the next sessions

| Parcel | Concrete output and acceptance evidence | State |
|---|---|---|
| Original-unit baseline | Revision/serial, photos, board markings, component labels and measured dimensions; agree comparison tolerances | Needs original-unit access; asked user |
| HAT reconciliation | Compare pinned official schematic/BOM and PCB with the local reconstruction, head envelope and runtime; record every intentional deviation | Clock/rail/source corrections committed; PCBA DRC, exact installed revision and fit remain open |
| Servo and power | Establish installed variant, measured supply and firmware/register compatibility; resolve voltage failures before powered tests | Open; measurements not performed |
| IMU bridge | Identify original MCU/transceiver and board revision; compare protocol, register layout, timing and mechanical fit | Original identity unresolved; functional substitutes cannot close 1:1 |
| Procurement | Exact MPN/qty/kit contents, delivery-country quote, stock and lead time per line; reconcile bundled cables and fasteners | Bundled-lead arithmetic corrected and tested for 1/100/1000 robots; final basket pending identity and destination |
| Mechanical fidelity | Per-part comparison against pinned meshes and original-unit dimensions, with maximum error, critical fits and mass/inertia separately reported | Existing model/print evidence does not prove physical equivalence |
| Assembly validation | Fastener-to-hole map, harness route/lengths, range of motion, thermal and gait measurements on an assembled unit | Remains open |

The missing `ce-cad` entry was repaired on 2026-09-08 after the user authorized
continued work and the necessary tooling repair. The
[new source-backed entry](../../../ce-cad/.claude/skills/ce-cad/SKILL.md)
is explicitly labelled a reconstruction, routes to the existing authoritative
rules, and is installed through symlinks in both Claude and Codex skill roots.
Validation and source-link checks passed. It does not claim recovery of the
lost original or verification of any physical design. The mandatory-entry
tooling blocker is closed.

## Coordination record

User authorized collaboration with the other local Codex/Claude instances.
Codex child agents are working on electrical reconciliation, exact component
sourcing and drawing validation, with explicit file ownership. The local cockpit
on 127.0.0.1:8877 initially refused connection and later returned health OK. Its
Claude session records are historical metadata; its live Claude CLI check failed,
so they do not establish a running Claude session. Process-name inspection found
Codex processes but no Claude-named process. This does not prove no Claude app
session exists. No message delivery to an existing external session was verified.

The user subsequently authorized contacting Ming with files on WeChat.
[The bilingual inquiry package](../research/ming-handoff-2026-09-08/BRIEF.html)
contains reference attachments and requests original-unit evidence, exact parts,
DFM feedback and itemized prototype/volume quotations. Its manifest records
hashes and evidence limitations. Delivery status belongs in the package's
verification record; a prepared ZIP does not prove a message was sent.

The existing head-print session's
[September 8 handover](../out/print/HEAD-PRINT-2026-09-08-CODEX.md) reports a rigid
head print sent and unresolved TPU slicing. Its files and hardware were left
alone; print completion has not been independently checked here.

This document is the handover for other sessions. Claim a specific parcel and
file set before edits, check current mtimes/status, and do not infer live owners
from September 2 workflow IDs. Consume the existing verification and identity
reports with the correction above. Do not rerun the old manufacturing workflow
into another lane's drawings directory.

## Validation update — September 8

The 22:10 readiness refresh found 27 distinct existing drawing reports: the
shin passes all eight sheet gates and 26 fail; six expected drawing entries
are missing. The shin's canonical PDF contains six verified rendered views.
Its full drawing contract remains incomplete: individual feature locators,
shaded feature details and original/production measurements remain open.
Readiness therefore keeps the drawing NOT_YET despite its eight-gate PASS.
See the [canonical result](../out/drawings/microduck-shin/result.json).

The sourcing generator now subtracts verified packaged servo leads and rounds
remaining ten-packs over the full batch. The selected offer needs 1/10/100
extra ten-packs for 1/100/1000 robots. Alternative offers without verified
bundle evidence receive no inclusion credit. The rollup remains a partial
cost estimate, not a supplier quotation or a confirmed original-parts basket.

The [orientation audit](../research/hat-orientation-audit-2026-09-08.json)
corrects a historical fit claim: the 180° in-plane rotation preserves the four
mounting holes but moves GPIO/anchor centroids 23.010002 mm. The
[fit report](../out/internals/hat-fit.json) retains its historical collision
volumes but disqualifies that pose as interchangeable in the same fixed stack.
This source-coordinate check did not rerun collision geometry or test a unit.

The [conditional PCBA quote appendix](../research/hat-pcba-rfq-2026-09-08/APPENDIX.html)
reconciles 113 physical components and includes per-designator quantities for
1/100/1000 boards. Twelve verification checks passed. Its DRC run reports 40
J4 pad-to-hole clearance errors and nine library warnings, with zero unconnected
items. It also records the fabrication drawing/stackup copper conflict, missing
test-point purchase codes, DNP ambiguity and Y1 land-pattern discrepancy. It is
an engineering inquiry, not a manufacturing release.

The [servo power audit](../research/servo-power-audit-2026-09-08/AUDIT.md) confirms
the published runtime takes its 6.6–8.2 V battery observation directly from
servo register 144, while both standard XL330 variants specify 3.7–6.0 V. The
public HAT connects motor supplies to +BATT. Startup also writes shutdown 52
(0x34), excluding input-voltage bit 0 despite its comment. The audit supplies
a factory evidence procedure; no runtime masks or physical rails were changed.

The [updated Ming review packet B](../research/ming-handoff-2026-09-08/update-b/READ-FIRST.html)
contains the original package unchanged plus hashed engineering attachments,
including the public fabrication archive and the later engineering audits.
[Delivery status](../research/ming-handoff-2026-09-08/update-b/delivery.json)
is **sent — UI observed**: the named ZIP appears as an outgoing file in Ming
Chan's WeChat conversation and the composer is empty. Recipient read/download
and a reply remain unknown. A parallel local session also delivered the
[parts inquiry](../research/ming-parts-request-2026-09-08/DELIVERY.json).
The archive is frozen; its builder now refuses to overwrite a sent packet.

Later coordination evidence supersedes the initial unknown-reply status:
Ming asked “How many virusses are in there?” at 21:55. Root inspected the
parallel session's [conversation capture](../research/networking-2026-09-08/ming-reply-outgoing.png),
which also shows its reply offering plain-text details and asking for trusted
supplier introductions. No engineering quotation or component confirmation is
established by that exchange. The parallel session also records a successful
Claude CLI drafting result. Its networking files remain owned by that session;
this record does not duplicate outreach or modify the frozen delivery snapshot.

The [fastener endpoint audit](../research/fastener-endpoint-integrity-2026-09-08/AUDIT.md)
maps all 64 modeled screws to explicit source-mesh pilot anchors. Five endpoint
and six thread-confidence regressions pass. This repairs reference integrity;
thread identity, stack qualification and torque remain unverified. The nominal
buy list still omits 23 modeled screws by size.

The [harness audit](../research/harness-route-confidence-2026-09-08/)
retains historical modeled lengths but removes unsupported physical cut lengths
and totals. Six route-confidence regressions pass. The zero-length stacking
header is not a cable; no physical loom has been measured.

Whole-kit battery purchasing and conditional ToF selection raise the partial
per-robot sourcing subtotals to USD 641.4564 / 612.4949 / 611.3793 at quantities
1 / 100 / 1000. These are source-based estimates, not landed quotations or a
verified original-component basket. The [power/ToF audit](../research/tof-power-sourcing-2026-09-08/REPORT.html)
records package quantities, interface mismatches and unresolved current ratings.

The test plan is NOT_YET. Its defined 42 end-of-line gates do not establish
physical test completion. The connected-servo high-voltage procedures require
correction and verified original power/servo identity before execution.

The [original CAD access audit](../research/original-cad-access-2026-09-08/REPORT.html)
maps all 43 source sidecars: 37 / 3 / 3 parts belong to three different CAD
microversions. The old single-version source note now has an additive correction.
These IDs do not identify production revisions. A fresh isolated browser redirects
to Onshape sign-in and anonymous API calls return 401/403; no original STEP/BRep
was acquired. Existing public source files and their hashes remain preserved.

The refreshed structural shelf check now reports 18 PASS / 54 CANNOT DETERMINE /
0 FAIL across 72 references. Four stale metadata hashes were reconciled without
changing physical findings. The [eye-ring correction](../research/eye-evidence-correction-2026-09-08/REPORT.md)
withdraws misclassified positive evidence through an audited, append-only CLI;
all eight historical rows and geometry bytes remain unchanged. Its final T1 is
simulation evidence, not physical acceptance. Structural PASS is kept separate
from manufacturing readiness throughout the factory report.

A read-only live farm refresh confirmed the independent head-print job at 16%,
running without a reported print error. Its V9 artifact hash matches the reviewed
file; see the [scoped observation](../out/handover/HEAD-JOB-OBSERVATION-2026-09-08.json).
This establishes continued printing, not completed parts, adhesion quality or
dimensional acceptance. The print-owning session retains control of the job.

The three omitted nominal fastener sizes now have
[conditional source routes](../research/fastener-source-routes-2026-09-08/REPORT.html)
with whole-package quantities. These remain model candidates; original threads,
material, grade and ROBOTIS TAP equivalence are not established.

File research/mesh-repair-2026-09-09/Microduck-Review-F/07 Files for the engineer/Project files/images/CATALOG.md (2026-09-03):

# Microduck (Pollen Robotics / Hugging Face) — visual reference catalog

Collected 2026-09-01. All Microduck stills and video frames live in this directory. Sources:
- Product page `https://pollen-robotics.com/microduck/` (Next.js site; assets under `/assets/microduck/…`)
- Press kit `https://pollen-robotics.com/microduck/press-kit/` (original full-res JPGs in `press/`, whole kit unzipped in `press/kit/`)
- Blog `https://pollen-robotics.com/microduck/blog/introducing-microduck/`
- Store `https://store.pollen-robotics.com/products/microduck` (Shopify CDN, 2400 px product shots in `store/`)
- GitHub `pollen-robotics/microduck` README media (`github/`), `pollen-robotics/microduck_rl` (**full MJCF + STL meshes of the real robot** — see `../cad/`)
- Press: TechCrunch (same as press_morning), Engadget, The Register, Interesting Engineering, Highleap (`press_ext/`)
- X/Twitter launch post `x.com/pollenrobotics/status/2092915032052879425` (video thumbnail only)

Video keyframes (1 fps) are in `frames/<video>/NNN.png`; contact sheets in `sheets/`.

Colourways (press kit, calibrated): Cream `#f7e6cb` (orange trim/beak, yellow-orange sole), Graphite `#6c6a68` (yellow trim/beak, lavender sole), Lavender `#bfa9cf` (yellow trim/beak, cyan eye ring), Sky `#a9dbe8` (orange trim/beak, yellow eye ring). Eye-ring colour = the contrasting accent, not the shell colour.

Published numbers: **25 cm tall, 14 cm wide, under 800 g (store: 780 g), 15 motors (Dynamixel XL330-M288-T visible on labels)**, front camera, 8x8 ToF LiDAR, 2 IMUs (body + head), articulated grasping beak, mic + speaker, 2 NFC antennas (head + beak), removable NP-F550 battery (2600 mAh, ~1 h), RK3566 + NPU, 1 GB RAM / 32 GB, Wi-Fi/BT. Mechanical files are NOT open-source hardware (press kit says so explicitly) but the RL repo ships the simulation meshes.

---

## Global anatomy (consistent across every image)

- **Head**: a "D"-profile loaf. Flat vertical front face (grey inset panel, slightly translucent-looking matte grey), dome top sloping down to a rounded rear, flat sides. Shell is a two-piece split: top shell (colour) + bottom shell (colour) with the **beak/trim colour band** sandwiched at the split line. Single **eye = camera**: 30 mm accent-colour ring (a cone/dish "noenoeil" part) with the M12 lens dead centre of the face. A small **pill-shaped dark window** to the viewer-right of the eye (ToF LiDAR / REC LED). Face panel is a separate grey part inset ~1 mm inside the shell lip.
- **Beak**: two flat plates in the accent colour. Upper beak is fixed to the bottom head shell (a lip ~10 mm deep all round the underside of the head). Lower jaw is a separate flat plate, hinged at the rear-sides of the head by two accent-colour **side brackets with 4 screws each** (visible on both sides near the rear of the head). Jaw opens ~25 mm at the tip. Under-side of jaw has a soft (TPU) pad; a soft "mouth top" pad sits opposite it.
- **Neck**: fully exposed stack of two black XL330 servos joined by grey folded-sheet brackets (neck pitch at the trunk, head pitch above), then head yaw + head roll inside the head. No cover. Cables visible.
- **Trunk**: rounded pill / soap-bar shell in shell colour, split **left/right** down the centre line (visible seam on the top front in `press_screentime`). One small round hole on each side of the top rear (button / LED / mic). Below the shell the hip mechanism is open: grey printed hip-roll clevis parts, two large flanged bearings, four black hip servos. **The NP-F battery hangs vertically at the rear of the trunk** (black block with rib, visible in back views) in a printed "power_support" cradle.
- **Legs (5 DOF each)**: hip yaw (in trunk, under shell) -> hip roll (grey clevis) -> hip pitch (black servo, outboard) -> knee (grey sheet shin) -> ankle (black servo sitting on the foot). The **thigh has a triangular cover plate** in shell colour with two screws; the shin is a bare grey 8 mm sheet with a big flanged bearing at the knee, exposed on the outside. Ankle servo is mounted vertically, its body forms the "shin" bottom.
- **Feet**: two-part. Top: accent-colour cap with a **triangular ankle bracket** (4 screws) rising from the middle and a slot on the top surface (roller-skate mount / NFC). Bottom: contrasting **rounded TPU sole**, ~13 mm thick, slightly larger than the cap. Foot is roughly 54 x 41 mm, rounded rectangle.
- **Fasteners**: countersunk/pan black M2 screws on servo horns (5-hole pattern), M2.5/M3 on shells. No visible vents; USB-C not visible externally (battery is the removable element; charger is external).
- **Finish**: FDM-printed shells (fine layer lines visible on close-ups, `press_stickers`, `store_*profile*`), matte. Grey structural brackets look like injection/printed grey plastic; the servos are Dynamixel black.

---

## Stills

| file | source | px | view | notes |
|---|---|---|---|---|
| `store/store_microduck-cream-standing-profile-left.jpg` | store | 2400x2400 | **pure left side view**, white bg | BEST side reference. Head loaf shape, beak sandwich, jaw side bracket (4 screws), exposed two-servo neck with "DYNAMIXEL XL330-M288-T" labels, trunk pill, battery ribs behind trunk, thigh triangle plate (2 screws), knee bearing, vertical ankle servo, foot cap + sole, sole slightly proud of cap. Pixel measure: head length = 0.42 of total height (graphite twin: 0.39); head sits pitched ~20 deg down. |
| `store/store_microduck-graphite-standing-profile-right-02.jpg` | store | 2400x2400 | pure right side view | Same as above mirrored, graphite/yellow/lavender. Shows the rear-of-head split line and that the jaw bracket sits at the rear-bottom corner. |
| `store/store_microduck-graphite-standing-back-three-quarter-right-02.jpg` | store | 2400x2400 | **rear 3/4** | BEST back reference. Shows: rear of head is plain rounded, trunk shell rear, black NP-F battery with two vertical ribs sitting in a cradle behind the trunk, hip servos, both thigh plates, knee bearings (large flanged bearing on shin outer face), ankle bracket screws, foot slot. |
| `store/store_microduck-sky-standing-three-quarter-left-02.jpg` | store | 2400x2400 | **front 3/4, jaw open** | BEST front-3/4. Jaw open ~25 mm; both beak plates flat with rounded corners; grey face inset; eye ring cone; ToF pill window right of eye; hip clevis parts; foot slot; neck labels. |
| `store/store_microduck-cream-sitting-three-quarter_1.png` | store | 2400x2400 (alpha) | front 3/4, SIT pose | Knees folded, feet forward showing soles; underside of thigh plate; knee servo horn; ankle bearing. |
| `store/store_microduck-lavender-sitting-three-quarter-left-04.jpg` | store | 2400x2400 | front 3/4, SIT, jaw open | Clear view of the two beak plates from below, hinge brackets, hip clevis geometry, foot cap vs sole colour split, thigh plate outline. |
| `store/store_microduck-4-colors-standing.png` | store | 1589x1589 | four robots, front 3/4, desk | Colourway reference; Reachy Mini poster on wall (no scale use). |
| `store/store_microduck-squad-sitting.png` | store | 1651x1651 | four robots, mixed poses | Front view of cream unit (eye centred on face, ToF at right); book stack (approx 22-24 cm tall) for scale. |
| `store/store_microduck-inside-the-box.png` | store | 1254x1254 | **true front (top-down flat-lay)** with NP-F550 battery, USB-C cable, gamepad | Scale reference: NP-F550 = 70.8 x 38.4 mm. Eye ring is exactly on the head centreline; ToF window to the right. Battery long side ~275 px, head width ~430 px -> ~110 mm apparent (flat-lay perspective; CAD says 92 mm). |
| `store/store_microduck-cream-standing-office.png` | store | 3060x3060 | front 3/4 close, desk | Best close-up of layer lines, jaw bracket 4-screw pattern, eye cone depth, ToF window shape (rounded slot ~8 x 4 mm), the small round hole on trunk top, two big grey hip parts, knee bearing. |
| `store/store_microduck-cream-standing-sleeping-room.png` | store | 3317x3317 | front 3/4 low angle | Same details, carpet. Shows trunk top opening where the neck servo enters (rectangular cut-out). |
| `store/store_microduck-lavender-standing.png` | store | 1023x1023 | front 3/4, jaw open | Small; colourway ref. |
| `store/store_microduck-sky-standing.png` | store | 1023x1023 | front 3/4 | Small; colourway ref. |
| `store/store_microduck-cream-playing-with-game-controller.png` | store | 3441x3441 | front 3/4 outdoors, second (graphite) unit behind | Woman kneeling with gamepad for scale (robot ~ knee height when kneeling). |
| `store/store_microduck-simulation-mujoco-office.png` | store | 1412x1412 | robot + MuJoCo screen | Shows sim twin; robot rear-3/4 small. |
| `press/press_closeup.jpg` | press kit | 2047x3640 | front 3/4 low angle, desk | Very sharp. Head loaf, eye cone, ToF pill, jaw bracket, neck servos + sheet brackets, trunk pill with seam, hip clevises, both feet. Keyboard behind (key pitch 19 mm) for scale. |
| `press/press_desk.jpg` | press kit | 4233x2380 | workbench, 4 partially assembled robots | **Detail gold**: bare head interior (lavender unit, camera module on a small PCB with lens holder visible through open face), trunk shells removed showing servo stack, spare foot caps and soles, XL330 servos, Xbox controllers (~150 mm wide) for scale. |
| `press/press_morning.jpg` | press kit | 4240x2650 | side/front 3/4 on desk | Clean profile-ish; second robot's bare head interior in foreground (yellow shell off, camera board visible). Also used by TechCrunch. |
| `press/press_kickabout.jpg` | press kit | 2768x1560 | three robots, side + front views | Sky unit side view with stickers; cream held by hand (scale: adult hand spans the whole head ~12 cm); graphite front view. Ball ~65 mm. |
| `press/press_stickers.jpg` | press kit | 2281x4057 | head close-up in hand | **Head detail**: layer lines, grey face panel inset, eye cone, ToF window, jaw side bracket. Thumb for scale (head ~ 2.5 thumb-widths). Also foot sole/cap junction. |
| `press/press_watching.jpg` | press kit | 2034x3617 | front 3/4 | Sharp; shows neck sheet bracket hole pattern, thigh plate screws, foot slot, ankle bearing. |
| `press/press_playtime.jpg` | press kit | 2003x3562 | rear 3/4 with person | Top of head (plain dome), battery rear, both thigh plates. |
| `press/press_screentime.jpg` | press kit | 2281x4057 | front, SIT | **Best pure front**: symmetric; eye centred; trunk centre seam; hip clevises; soles facing camera (rounded rect, slightly domed). |
| `press/press_bedroom.jpg` | press kit | 2193x3901 | wide, person for scale | Robot on floor next to sitting adult: robot height ~ shin length. |
| `press/press_playroom.jpg` | press kit | 2281x4057 | front 3/4 walking | Mid-stride; thigh plate swing; foot roll. |
| `press/press_walkabout.jpg` | press kit | 2357x3143 | front 3/4 | Head slightly pitched; stickers on shell. |
| `press/press_carried.jpg` | press kit | 2219x3947 | side, held in hand | Hand wraps the trunk: trunk width ~ palm width (~80 mm). Graphite/yellow/purple feet. |
| `press/press_team.jpg` | press kit | 2000x2667 | team photo, 2 robots | Robot height vs shoe: ~ 1x shoe length -> 25-28 cm. |
| `blog_scale-in-hand.webp` | blog | 1600x900 | front 3/4, hand on trunk | Scale: adult hand; robot head about a hand-length wide. |
| `blog_cover-microduck.webp` | blog | 1200x896 | (cover) | Marketing. |
| `blog_sim2real-poster.jpg` | blog | 1600x900 | sim/real split | Sim render matches CAD; real sky unit. |
| `launch-film-poster.jpg` | site | 1920x1280 | four people + robots outdoors | Scale vs people. |
| `pack-robot.webp` | site | 880x587 | illustration | In-box contents drawing. |
| `pack-dev.webp` | site | 880x587 | illustration | Dev pack: 3 spare XL330-style servos, 5 JST cables, 2 NP-F batteries, dual charger, 10 NFC tags, screwdriver, screws. |
| `pack-accessories.webp` | site | 880x587 | illustration | Accessory pack: **2 roller-skate modules** (yellow tray with 2 wheels each, clip onto feet), ball, laser pointer, NFC polaroid, 10 NFC tags. |
| `pack-charger.webp` | site | 880x587 | illustration | Dual NP-F charger + 2 batteries + USB-C. |
| `squad.webp` / `github/gh_readme_5.webp` | site / README | 1839x638 | 4 colourways cut-out | Side/3-4 views of all four. |
| `og_og-microduck-squad-v2.jpg` | site | 1200x630 | social card | Same squad. |
| `moves-portrait-alpha_posters_{walk,grab,drive,standup,sitstand,kickL}.png` | site | 800x1280 (alpha) | **CAD renders** (transparent) | Rendered from the same model as the MJCF; walk = front 3/4 standing; grab = crouched with jaw at floor; drive = front with roller-skates; standup = 3/4 rear. Clean silhouettes for tracing. |
| `gallery_*.webp` | site | 1012x1800 etc. | same shots as `press/` at lower res | Duplicates. |
| `gallery_*-poster.jpg` | site | 1280x720 | video posters | See frames. |
| `press_ext/engadget_intro.jpg` | Engadget | 1600x898 | = press_kickabout crop | |
| `press_ext/register_5293032.jpg` | The Register | 2000x1250 | = press_desk | |
| `press_ext/ie_cover.jpg` | IE | 1920x1080 | = press_kickabout | |
| `press_ext/hil_microduck.webp` | Highleap | 1206x418 | 4 colourways | Cut-outs. |
| `press_ext/hil_microduck-1.webp` | Highleap | 726x590 | lavender 3/4 + squad | |
| `press_ext/x_video_thumb.jpg` | X post | 1080x720 | launch-film frame | Bedroom scene, robot small. |
| `github/gh_readme_7.png` | microduck README | 2215x884 | sim vs real side view | Sim shows leg linkage clearly. |
| `team.webp`, `team-square.webp` | site | 1500x2000 | team | Scale only. |
| `stickers_*.webp`, `press/kit/STICKERS/*` | site | small | die-cut stickers | Not mechanical. `duck-head-mark*.webp` = head icon (silhouette reference for the head profile: flat face, domed back, beak lip). |

## Video frames (`frames/…`, sheets in `sheets/`)

| video | res / len | what it shows |
|---|---|---|
| `microduck-hero.mp4` (15 s, 1920x1080) | hero | sticker application on head (close-ups of the head shell top, eye cone); roller-skate clip-on being fitted to the foot (**skate module = yellow/orange tray with two wheels that clips under the foot cap, ankle stays**); skate park low angle. |
| `launch-film.mp4` (51 s) | launch film | bedroom walk; **get-up from lying on back** (frames 9-11); train-on-monitor; grab (jaw picks a sock, frames 17-19); four-robot line-up front view (43-48) — good for front silhouette of all four colourways; skate. Watermark "Prototype shown. Final product may vary". |
| `gallery_squad-standup.mp4` (33 s) | four robots stand up from lying, living room | many mid-transition poses; shows underside of feet and folded legs. |
| `gallery_balance-recovery.mp4` (13 s) | push recovery | sagittal-plane views mid-step. |
| `gallery_grab-and-carry.mp4` (10 s, portrait) | grab a sock, carry to box | whole-body crouch; jaw open at floor; NOTE jaw opens downward only (upper beak fixed). |
| `gallery_roller-skating.mp4` (11 s) | skating in living room | skates fitted; legs in "swizzle" motion. |
| `gallery_chorale.mp4` (12 s) | four robots, jaws moving | jaw range; head roll/yaw expressiveness. |
| `blog_sim2real.mp4` (24 s) | split sim/real | sim renders match physical robot: same foot/leg shapes. |
| `microduck-card.mp4` (13 s) | homepage card | recut of hero. |
| `github/gh_readme_4.mp4` (33 s) | README | roller-skating demo, living room. |
| `github/gh_readme_6.mov` (61 s, 1280x720) | README | **earlier prototype pair** (cream/yellow with purple eye and the cream/orange): head slightly boxier, small yellow "ear" nubs = jaw hinge brackets; shows standing, walking, head yaw, jaw open, sit. Legs identical to production. |
| `moves-portrait-alpha_*.webm` | site | CAD-rendered move loops on black (walk, sitstand, drive, grab, standup, kickL); clean orthographic-ish 3/4 renders for silhouette tracing. |

## CAD renders of the published MJCF (`../cad/renders/`)
`STAND_front.png`, `STAND_side.png`, `STAND_back.png`, `STAND_top.png`, `INIT_front.png` — orthographic, 4 px/mm, 50 mm grid, generated from `microduck_rl/robot_walk.xml` + STLs. These are exact geometry (alpha CAD; production shell colours differ but shapes match photos).

---

## Internals — what exists and what does not (appended 2026-09-03 by the src-internals lane)

Leif asked for "an new image covering the components of the microduck internals". Searched 2026-09-03
(full log with URLs and dates: `out/sources/internals.json` → `search_log`): MakerWorld 3250889, Pollen's
site/press kit/blog, both Pollen GitHub repos (zero image files in either tree), the HF
`mishig/microduck-anatomy` space (simulator meshes), the fanhao375 replica exploded drawings (MJCF-derived,
"unverified against physical hardware"), the bilibili "硬件架构拆解" video (a pre-ship analysis), and
EN/ZH web search. **No public photograph or diagram of the full internal layout exists** — units ship at
Christmas 2026. What DOES exist is two press-kit photographs of partially disassembled units, already in
this directory; the lane cropped them at 2x into `out/sources/internals/`:

| crop | from | shows |
|---|---|---|
| `real_desk_head_jaw_off.png` | `press/press_desk.jpg` (560,870)-(1260,1400) | lavender unit, lower beak removed: a green camera PCB standing vertically behind the face plate, the mouth-servo XL330 under it (label readable), the eye ring + M12 lens |
| `real_desk_trunk_shells_off.png` | `press_desk.jpg` (0,600)-(560,1330) | cream/mint unit, trunk shells off: two XL330 stacked, a small dark PCB with white silkscreen ("3V" legible) on the trunk plate below them, mint yaw2roll clevises with 22 mm flanged bearings; behind it an orange top head shell upside down showing its interior ribs |
| `real_desk_head_yawroll_stack.png` | `press_desk.jpg` (2450,180)-(3200,780) | graphite/orange unit lying down: the head yaw/roll servo pair with its printed brackets, cabling, and a graphite trunk shell |
| `real_desk_top_shell_interior.png` | `press_desk.jpg` (2400,120)-(2900,620) | inside of an orange top head shell |
| `real_morning_head_rear_open.png` | `press/press_morning.jpg` (3050,1100)-(4240,2000) | yellow bottom head shell seen from behind, the rectangular neck opening with the yaw/roll servo stack inside |

Our own labelled internals (see-through, shells-off, exploded, cable routes) are `INTERNALS.html`
(tools/gen_internals.py from out/sources/internals.json, renders by tools/internals_render.py).

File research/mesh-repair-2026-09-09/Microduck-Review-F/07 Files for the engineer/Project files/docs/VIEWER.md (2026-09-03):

# The microduck bench — open it, move it, play it

**http://localhost:8765/web/microduck.html**

One page that answers the three questions a render cannot: *what parts are in
there*, *what can it move*, and *does the policy actually walk*.

```bash
# the dashboard already runs under launchd; if it is not up:
~/dev/ce-workshop/ce-cad/bin/dash          # -> http://localhost:8765/web/
open -a "Google Chrome" http://localhost:8765/web/microduck.html
```

Nothing else to start. It is a second page on the ce-cad dashboard, so it
shares the dashboard's port, its vendored three.js and its theme — the
assembly card is one click away in the header, and every part row links back
to its own card and to `/api/files?id=part:...`.

## What it does

**See every part.** 70 placed parts over 15 bodies, 817,902 triangles, each
one pickable. Hover for its name, click for its card — body, the hinge that
drives it, triangle count, the mesh file on disk, its triad ref, and links to
its dashboard card and its files. The left panel lists them grouped by body;
`ours only` hides everything Pollen supplied and leaves the 33 parts this repo
rebuilt (they are orange in the scene and tagged OURS in the list). `explode`
pulls the assembly apart along each part's own outward direction; `x-ray the
shells` makes the trunk and head shells transparent so the XL330s, the battery
and the boards are visible without hiding anything.

**Move the mechanics.** One slider per actuated hinge, all fourteen, grouped
left leg / head+neck / right leg. Each is wired to the real axis and the real
range: the green band on the track is what the servo has, and the slider
deliberately travels 45° past each end so you can try to go further. It
clamps, and it says so — *"CLAMPED — commanded +88.0°, the hinge stops at
+30.0° (range −25…+30°)"*. Child links follow their parent, because the page
runs MuJoCo's own composition, `T(body.pos) · R(body.quat) · R(axis, θ)`, down
the same tree the MJCF declares. `hinge axes` draws all fourteen axes as
arrows attached to the bodies they turn, so they move with the mechanism.

Presets: **STAND · SIT · FOLD · INIT · ZERO** (keys 1, 2, 3, 0), read from the
MJCF's own `<keyframe>` block, not typed in here.

**Play the simulation.** Six recorded MuJoCo runs are on the transport, chosen
from the dropdown and scrubbable frame by frame:

| trajectory | frames | what it is |
|---|---|---|
| `walk_ours` | 401 @ 50 Hz | `BEST_alpha_walking.onnx`, vx 0.25 m/s, walked 0.7925 m |
| `sitstand_ours` | 401 | the sit/stand cycle |
| `stand_from_sit_ours` | 301 | standing up from SIT |
| `stand_from_fold_ours` | 301 | standing up from FOLD |
| `stand_hold_ours` | 201 | standing and holding |
| `walk_stock` | 401 | the same policy on Pollen's stock parts, for comparison |

Space plays and pauses. The sliders follow the sim while it runs, the root
position and orientation come from the free joint's own qpos, and the readout
carries the clock, the frame, the root x and z in metres, and the distance
walked. If any sample in a recording asks for an angle the hinge does not
have, the transport says how many and clamps them rather than drawing a pose
the robot cannot reach.

## Deep links — a pose is a URL

```
?pose=SIT
?traj=sitstand_ours&frame=250&play=1
?joint=left_knee:-45&joint=head_yaw:90
?part=microduck-hip-bracket&isolate=1
?explode=90     ?axes=1     ?xray=1
```

They compose. This is also how the proof shots are taken, so a picture in
`out/viewer-proof/` can be reproduced by opening its URL.

## Where the data comes from

Nothing on the page is authored. `tools/export_viewer.py` reads the files that
are already the truth and writes into the dashboard's served tree:

| written | from |
|---|---|
| `ce-cad/out/web/microduck/scene.json` (53 kB) | `sim/microduck_ours.xml` — tree, hinges, 70 visual geoms, materials; `spec/mesh-to-part.json` for the part refs; `out/sim/scene_walk_ours.xml` for the keyframes |
| `ce-cad/out/web/microduck/geom.bin` (5.46 MB) | the 38 distinct STLs, welded, float32 positions + uint16 indices |
| `ce-cad/out/web/microduck/traj-*.json` | `out/sim/*_traj.npz` — qpos, degrees per frame (the browser cannot open an npz) |

```bash
cd ~/dev/ce-workshop/ce-designs/microduck
python3 tools/export_viewer.py         # ~1 s, pure stdlib — no MuJoCo, no FreeCAD
node   tools/shoot_viewer.mjs          # re-take the proof shots
```

The exporter **cross-checks itself**: it walks the MJCF tree to the world pose
of every hinge and compares that against the MEASURED rows in
`ce-assemblies/microduck/current/joints.json`. Measured 2026-09-02: **14 of 14
AGREE** — worst origin delta 0.000 mm, every axis dot ±1.000000 — and the
header chip on the page states that count. A disagreement would be printed by
name, not swallowed.

## One thing that does not work, and why

`cecad.shots` / `cecad.vision.screenshot_url` **cannot photograph this page.**
Its long-lived Chrome is started with `--disable-gpu`
(`ce-cad/web/shotd.mjs:185`), so the browser hands out no WebGL context at
all. MEASURED 2026-09-02, same URL, same port: under shotd the page's ready
handshake never went true (`ready_ms` 45232, the entire budget); in a Chrome
launched without that flag it was ready in 9 s and drew 817,902 triangles.
This is not specific to microduck — it applies to any WebGL page on this
machine, the dashboard's own 3D viewer included.

Two things came out of that rather than a workaround:

1. **The page states the absence instead of hanging.** With no WebGL it still
   loads the data, still builds the parts list, the sliders and the
   transport, prints *"no WebGL in this browser"* with the reason across the
   stage, and sets `window.__mdReady.webgl = false` — so a prober gets a
   definite answer in a second instead of burning its whole budget on a page
   that will never be ready.
2. **`tools/shoot_viewer.mjs`** reuses ce-cad's own CDP driver
   (`ce-cad/web/_cdp.mjs`) and drops that one flag. It waits on the page's own
   ready handshake, refuses to file a PNG under 20 kB, and exits non-zero if
   any shot did not draw.

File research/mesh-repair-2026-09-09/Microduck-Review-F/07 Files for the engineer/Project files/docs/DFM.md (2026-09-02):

# DFM — the 20 rebuilt Microduck parts, measured for FDM

**Set.** Every part whose `ce-parts/<slug>/component.json` says
`record.origin = "generated"` **and** `record.verdict = "PASS"` — 20 parts.
Nothing else is in this table: a vendor mesh is not a rebuild and a decimated
mesh has no callable dimension.

**Measured** 2026-09-02 under `ce-cad/bin/cad`, on the PARAMETRIC SOLID loaded
by `cecad.triad.load("part:<slug>")` — not on a mesh someone shipped us:

| what | by | where it lands |
|---|---|---|
| bed fit, upright, thinnest wall vs two perimeters, modelled filament | `cecad.printed.printability` | `out/dfm/dfm-rebuilt.json` → `printability` |
| exact thinnest wall + the point it occurs at | `cecad.inspect.thinnest_wall_detail` | → `thinnest_wall_detail` |
| every hole: Ø, axis, depth, through/blind | `cecad.inspect.holes` | → `holes` |
| figures + verdict roll-up | `cecad.dfm.measure(slice=False)` | → `dfm_measure` |
| subtractive plan | `cecad.machining.plan` | → `machining` |
| **overhang and support area, six build directions** | `tools/dfm_rebuilt.py` + `tools/dfm_orient.py` on this solid's own tessellation | → `mesh`, `orientation` |
| **grams and seconds** | the print farm's OrcaSlicer, already run | `out/print/slice.json` |

Bed for the geometry checks `prusa_mk4` (250 x 210 x 220); nozzle 0.4, layer
0.2, two-perimeter floor **0.80 mm**. The farm that actually sliced these is a
**Bambu Lab H2S**, 0.4 nozzle, `0.20mm Standard @BBL H2S`, PLA 1.26 g/cm3.

---

## How to read the columns — and what each one is NOT

**Orientation is MEASURED, and the first way we measured it was wrong.**
`ce-cad` has no overhang tool — `printed.printability` says so in as many
words ("It does NOT check overhangs or warping") — so overhang is computed here
from facet normals: for a down-facing facet with unit normal `n` and build-up
direction `u`, `d = -(n.u)` and `beta = acos(d)` is the facet's angle to the
build plate. `beta < 30 deg` is BambuStudio's default support threshold,
`beta < 10 deg` is a flat down-face (a bridge or a floating island).

The first pass ranked the six axis-aligned directions on total `beta<30` area,
and it produced a **wrong answer from a correct measurement**: a part's flat
bottom is a `beta = 0` face, so `microduck-trunk-base` — a 57 x 36 x **3 mm**
plate — scored 43.7% overhang lying flat and 2.4% standing on its 57 mm edge,
and the ranking recommended printing a 3 mm plate 285 layers tall. The bed is
not support material. `tools/dfm_orient.py` therefore splits the `beta<30` area
into **on the plate** (every vertex within one first layer of the part's lowest
point) and **elevated**, and ranks on elevated area only. The naive answer is
kept in the JSON as `naive_best_bed_counted` so the correction stays auditable.
`orient()` re-checks itself on a 10 mm cube (100 mm2 down-face, 100 on the bed,
0 elevated; four vertical walls that must not count) and on a slab standing on
four legs (4 mm2 bed, 100 mm2 elevated) before it will report anything — and
that check **failed on its first run**, on an assertion of 96 that should have
been 100, which is the only reason the numbers below are worth anything.

**Support area is an UPPER BOUND.** An elevated down-face spanning between two
walls is a bridge and prints; one with nothing under it is an island and does
not. Nothing in `ce-cad` tells them apart, and this does not either.

**Thinnest wall: read the exact figure AND the ray percentiles.**
`inspect.thinnest_wall` is exact and reports the single thinnest place on the
solid, which on a chamfered part is a **knife-edge** — a face tapering to a
tangent line, which the slicer rounds off. So the table also carries `p1` and
`p5` from 4000 seeded internal rays (`seed 20260902`): `p1 >= 0.80` means the
sub-0.8 exact reading is a sliver and the part has no thin wall; `p1 < 0.80`
means it really does. Both are reported; neither is laundered.

**Grams are SLICED, by the farm.** `printability`'s modelled shell+infill
figure is in the JSON but is not the authority and is not what the table
quotes. Where `stl_source` says *vendor mesh*, the slicer was run on Pollen's
mesh, not on our rebuild — flagged in the per-part list.

**Machining CANNOT DETERMINE on all 20 is the CORRECT result**, and it now says
why in its own words: *"fdm is ADDITIVE — the findings this module measures
(internal corners, tool reach, depth ratios) do not constrain it."* These are
printed parts. The empty machining verdict confirms that; it does not
contradict it.

**Verdict rule**, applied mechanically, not by feel:

- **PRINTABLE** — fits the bed, **and** needs 0 mm2 of support in the chosen
  orientation, **and** ray `p1 >= 0.80 mm` (no real sub-two-perimeter wall).
- **PRINTABLE-WITH-CARE** — fits and prints, but carries at least one measured
  risk: support needed, a real wall under 0.80 mm, a bore across the layers, a
  thin moving feature, or a foot too small to hold the part down.
- **CANNOT DETERMINE** — a required measurement is missing.

---

## Summary table

Orientation is the build-up direction in the part's own frame, chosen on
elevated support area. "Wall" is exact / ray-p1. "Support" is elevated
`beta<30` mm2 in that orientation; "foot" is bed contact.

| Part | Mat | Fits bed | Print orientation | Wall exact / p1 (mm) | Sliced g | Support mm2 | Foot mm2 | Print risks | Verdict |
|---|---|---|---|---|---|---|---|---|---|
| **power-support** | PLA | yes | **+Z upright**, 83.1 mm, 416 L | **0.800 / 0.7998** | 13.15 | **969** | **10.6** | stands on the 10.6 mm2 latch-tongue tip; 437 mm2 head-shelf ledge; 2 flange ledges; 0.466 mm latch slits; 10 M2 tap holes across the layers | PRINTABLE-WITH-CARE |
| shin | PLA | yes | +Z, 58.0 mm, 290 L | 0.028 / 0.804 | 3.60 | 203 | **3.6** | foot is 3.6 mm2 — will not stay on the bed without a brim; all 15 bores across the layers | PRINTABLE-WITH-CARE |
| trunk-base | PLA | yes | +Z flat, 3.0 mm, 15 L | 1.000 / 1.000 | 1.82 | **0** | 1397 | none measured; all 6 holes up the build axis | **PRINTABLE** |
| banana-pcb-locker | PLA | yes | -Y flat, 3.8 mm, 19 L | 0.921 / 0.922 | 0.68 | **0** | 290 | 54 mm long, 1.5 mm thin bar — handling, not printing | **PRINTABLE** |
| bearing-roll | PLA | yes | +Y flat, 3.0 mm, 15 L | 0.900 / 1.000 | 0.85 | **0** | 616 | none measured; Ø19 bore up the build axis | **PRINTABLE** |
| yaw2roll | PLA | yes | -Y, 25.8 mm, 130 L | 0.198 / 0.794 | 2.96 | 108 | 242 | 8 bores across the layers incl. Ø4.84 horn seats; p1 0.794 grazes the floor | PRINTABLE-WITH-CARE |
| upper-leg-left | PLA | yes | -X, 28.0 mm, 140 L | 0.024 / **0.101** | 4.67 | 190 | 1533 | **thinnest real wall in the set** — p5 0.478 mm, under two perimeters over 5% of the surface; Ø5.37 pivots up the axis | PRINTABLE-WITH-CARE |
| upper-leg-right | PLA | yes | +X, 28.0 mm, 140 L | 0.024 / **0.0885** | 4.67 | 190 | 1533 | mirror of the left, same wall problem (p5 0.460) | PRINTABLE-WITH-CARE |
| upper-leg-rigidity-plate | PLA | yes | +X flat, 1.0 mm, **5 L** | 1.000 / 1.000 | 1.00 | **0** | 740 | 5 layers total — must lie flat; warp/handling | **PRINTABLE** |
| hip-bracket | PLA | yes | -Z, 19.0 mm, 95 L | 0.800 / 0.920 | 3.81 | 237 | 134 | 22 bores, **every one across the layers**; densest part in the set | PRINTABLE-WITH-CARE |
| ankle-left | PLA | yes | +Y, 36.5 mm, 183 L | 0.234 / 1.202 | 6.18 | 163 | 82 | Ø15 + Ø14 bearing seat across the layers — bridged, oval, undersize | PRINTABLE-WITH-CARE |
| ankle-right | PLA | yes | +Y, 36.5 mm, 183 L | 0.234 / 1.202 | 6.18 | 163 | 82 | mirror; same bearing seat | PRINTABLE-WITH-CARE |
| foot-left | PLA | yes | -X, 40.1 mm, 201 L | 0.015 / **0.263** | 13.35 | **870** | 43 | most support work in the set after power-support; real sub-mm material in the rib comb | PRINTABLE-WITH-CARE |
| foot-right | PLA | yes | +X, 40.1 mm, 201 L | 0.015 / **0.324** | 13.35 | **870** | 43 | mirror; same | PRINTABLE-WITH-CARE |
| sole-left | TPU | yes | -Y, 54.0 mm, 270 L | 1.232 / 1.316 | 7.07 | 274 | 204 | TPU + 270 layers = the slowest part (2497 s); no holes | PRINTABLE-WITH-CARE |
| sole-right | TPU | yes | -Y, 54.0 mm, 270 L | 1.232 / 1.317 | 7.07 | 275 | 204 | mirror; same | PRINTABLE-WITH-CARE |
| motor-support | PLA | yes | -X, 73.5 mm, 368 L | 0.008 / **0.530** | 9.20 | **836** | 100 | tallest part after power-support; real sub-mm material; slicer says "floating cantilever" | PRINTABLE-WITH-CARE |
| neck-pitch-bracket | PLA | yes | +Y, 18.0 mm, 90 L | 0.376 / **0.339** | 4.38 | 146 | 264 | real sub-mm material; 19 bores, 15 across the layers | PRINTABLE-WITH-CARE |
| neck-plate | PLA | yes | +X flat, 2.0 mm, 11 L | 0.850 / 0.863 | 0.55 | **0** | 200 | 11 layers; tiny (0.55 g) | **PRINTABLE** |
| yaw-roll-motion | PLA | yes | -Z, 22.5 mm, 113 L | **0.750** / 0.850 | 4.71 | 207 | 698 | **exact wall 0.750 mm is genuinely under two perimeters** at (8.75, 8.02, 17.0); Ø12 bore across the layers | PRINTABLE-WITH-CARE |

**20 / 20 fit the bed** in their as-modelled orientation. **5 are PRINTABLE with
nothing to watch; 15 are PRINTABLE-WITH-CARE. 0 are CANNOT DETERMINE, and 0
fail.** Machining is CANNOT DETERMINE on all 20 — correct, they are FDM parts.

Total sliced, one piece of each: **109.26 g** and **22 723 s = 6 h 18 m**
of machine time (Bambu H2S, 0.2 mm, PLA/TPU) — summed from `out/print/slice.json`,
not from the modelled figures.

### Where `printability` says FAIL and this table does not

`printed.printability` returns `ok = fits and wall >= 0.80` and so reports
**FAIL on 10 parts** (ankle L/R, foot L/R, motor-support, neck-pitch-bracket,
shin, upper-leg L/R, yaw-roll-motion, yaw2roll). That flag is doing its job —
it cannot tell a knife-edge from a wall. The ray percentiles can, and on shin
(p1 0.804), ankle (1.202) and yaw2roll (0.794) the exact minimum is a chamfer
sliver, not a wall. The five where the thin material is **real** are
**upper-leg L/R (p1 0.10/0.09), foot L/R (0.26/0.32), motor-support (0.53),
neck-pitch-bracket (0.34)** and **yaw-roll-motion (exact 0.750)**. Both numbers
are in the table; the FAIL is not hidden and it is not obeyed blindly.

---

## Per-part print risks

### power-support — 54.5 x 17.0 x 83.1 mm, PLA, 13.15 g sliced, 2302 s
The hardest part in the set on every axis: tallest, most support, smallest
foot, the only moving printed feature. Full risk list below in its own section.

### shin — 8.0 x 20.0 x 58.0 mm, 3.60 g, 869 s
- **Foot 3.6 mm2.** Standing +Z (58 mm, 290 layers) is the least-support
  orientation (203 mm2) but the part touches the bed on almost nothing. A brim
  is not optional. The alternative the farm chose, "8 mm plate flat, rim walls
  up" (±X, 40 layers, 190 mm2 of bed), costs 696-831 mm2 of support instead —
  a real trade, both numbers measured.
- **All 15 bores run across the layers** in +Z: 4 x Ø2.20, 2 x Ø2.40, 1 x Ø2.70,
  4 x Ø4.40, 2 x Ø4.84, 1 x Ø5.50, 1 x Ø6.00. Each one's top arc bridges. The
  Ø6.00 and Ø5.50 are the knee/ankle pivots — ream them.
- Exact wall 0.028 mm at (35.87, 31.98, 14.88) is a knife-edge; p1 0.804 mm
  says the plate itself is sound.

### trunk-base — 57 x 36 x 3.0 mm, 1.82 g, 280 s
- **Zero support, 1397 mm2 of bed, 15 layers.** The easiest part here.
- All 6 holes (4 x Ø2.30, 2 x Ø19.00) run up the build axis: they print round,
  slightly undersize, and never bridge.

### banana-pcb-locker — 54.0 x 3.8 x 6.6 mm, 0.68 g, 140 s
- Zero support laid on its 54 mm face (19 layers, 290 mm2 of bed).
- Both Ø2.17 holes run up the build axis. Nothing bridges.
- 1.5 mm thin over 54 mm: the risk is snapping it off the plate, not printing it.

### bearing-roll — 23 x 3.0 x 40 mm, 0.85 g, 164 s
- Zero support flat; the Ø19 window and 4 x Ø2.20 are all axial. Prints clean.
- 0.9 mm minimum wall around the window is 2.25 perimeters — thin but real.

### yaw2roll — 23 x 25.8 x 20.5 mm, 2.96 g, 787 s
- 108 mm2 of support in -Y (130 layers), the least of the six directions.
- **8 bores across the layers**: 4 x Ø2.20 + 4 x Ø4.40. The Ø4.84 horn seats and
  Ø5.50 run up the axis in this orientation and print clean — that is the whole
  reason -Y wins.
- Exact 0.198 mm is a sliver, but p1 0.794 mm grazes the two-perimeter floor:
  the 1.4 mm walls the record describes have thin spots. Keep 2 perimeters
  minimum and do not thin this part further.

### upper-leg-left / upper-leg-right — 28 x 47.7 x 61.0 mm, 4.67 g each, ~918 s
- **The thinnest real material in the set.** Exact 0.024 mm is a knife-edge,
  but the rays say p1 = 0.1012 mm (left) / 0.0885 mm (right) and **p5 = 0.478 /
  0.460 mm** — over five per cent of the sampled surface is under half a
  millimetre, i.e. thinner than a single 0.4 mm perimeter can bridge cleanly.
  The record calls these "1 mm walls" and the median ray agrees (0.9986 mm), so
  the thin fifth is local, not global — but it is not a chamfer either.
  **This is the one part where the geometry, not the print, should be revisited.**
- Laying it on its side (-X left / +X right, 140 layers) buys 1533 mm2 of bed
  and cuts support from 745 mm2 (the naive upright answer) to 190 mm2.
- Both Ø5.37 hip/knee pivots run up the build axis in that orientation — they
  print round. Ream anyway if a shaft passes through.
- Slicer flag: "floating cantilever - enable supports".

### upper-leg-rigidity-plate — 1.0 x 45.0 x 58.1 mm, 1.00 g, 204 s
- **Five layers total.** Zero support, 740 mm2 of bed, wall a flat 1.000 mm
  everywhere (min = p1 = p5 = median). Print it dead flat; standing it on edge
  is 291 layers of a 1 mm wall and is not a real option.
- Ø19 windows and 4 x Ø2.20 all run up the build axis.
- Warp and handling are the risks, not the print.

### hip-bracket — 32.45 x 34.5 x 19.0 mm, 3.81 g, 1067 s
- **All 22 bores run across the layers** in every orientation that is any good
  (best is -Z, 237 mm2 support, 95 layers): 8 x Ø2.40, 8 x Ø4.84, 4 x Ø5.22,
  2 x Ø6.00. This is an L-bracket with a horn pattern and a bearing boss on
  **both** legs, so the two hole axes are perpendicular and no single build
  direction can put both up the axis. Ream the Ø6.00 bearing seats.
- Exact wall 0.800 mm = exactly two perimeters, no margin, at (17.52, -17.53, 7.20);
  p1 0.920 confirms it is a real wall, not a sliver.

### ankle-left / ankle-right — 39.5 x 36.5 x 25.5 mm, 6.18 g each, ~1315 s
- **The Ø15 + Ø14 bearing seat runs across the layers** (+Y, 183 layers, 163 mm2
  support — by far the best of the six). A bridged Ø15 comes out oval and
  undersize at the top. **Ream it, or the 15x10x3 bearing will not seat.**
- 13 bores total, **all** across the layers here: 5 x Ø2.20, 5 x Ø4.40,
  1 x Ø5.00, plus the Ø14/Ø15 pair.
- Exact 0.234 mm at (±32.5, 22.60, 0.92) is a sliver; p1 1.202 mm — no real
  thin wall.
- Slicer flag: "floating regions - enable supports". Sliced from the **vendor
  mesh**, not our rebuild.

### foot-left / foot-right — 40.1 x 54.0 x 16.9 mm, 13.35 g each, ~1972 s
- **870 mm2 of support** on its side (±X, 201 layers) — the second-worst in the
  set, and every other direction is worse (the flattest, ±Z, needs 1274-1460).
  The 10-rib comb bottom and the two snap fingers are the cost.
- **Real sub-millimetre material**: p1 0.263 / 0.324 mm, p5 1.06 / 1.12 mm. The
  exact 0.015 mm reading is the bottom sole chamfer at z = -16.65 and is
  cosmetic; the p1 is the comb.
- 1 x Ø1.60 M2 pilot + 1 x Ø3.00, both across the layers in this orientation.
  Drill and tap the Ø1.60 after printing.
- Heaviest single part in the set. Sliced from the **vendor mesh as shelved**.

### sole-left / sole-right — 41.1 x 54.0 x 12.9 mm, TPU, 7.07 g each, ~2494 s
- **The slowest parts in the set** — 2497 s each, more than the 83 mm
  power-support, because TPU is printed slow.
- 274 mm2 support, 204 mm2 bed, on its side (-Y, 270 layers). The farm printed
  them "sole tread face down, dead flat" instead and the slicer raised no
  warning; that is a defensible different call and it is the tread finish, not
  the support number, that should decide.
- No holes. Wall 1.232 exact, p1 1.316 — the soundest walls of the twenty.
- Sliced from the **vendor mesh as shelved**.

### motor-support — 73.5 x 54.2 x 18.8 mm, 9.20 g, 1265 s
- **836 mm2 of support and 368 layers** standing on its 73.5 mm edge — that is
  the best of six, and the flat option (±Z, 95 layers) costs 1077-1287 mm2.
  There is no cheap orientation for this frame.
- **Real thin material**: p1 0.530 mm. The exact 0.008 mm at (-28.95, -8.56, 6.68)
  is a knife-edge.
- 4 x Ø2.70 across the layers; the Ø17.65 lens tube runs up the axis.
- Slicer flag: "floating cantilever - enable supports". Sliced from the
  **vendor mesh as shelved**.

### neck-pitch-bracket — 35.0 x 18.0 x 27.7 mm, 4.38 g, 1185 s
- 146 mm2 support in +Y (90 layers), less than half the naive upright answer.
- **Real thin material**: p1 0.339 mm, p5 1.064 mm; exact 0.376 mm at
  (-14.10, -8.79, -21.87).
- 19 bores, 15 of them across the layers here: 12 x Ø2.20, 4 x Ø4.40 (axial),
  3 x Ø6.00. Ream the Ø6.00 bearing seat.
- Slicer flag: "floating regions - enable supports". Sliced from the
  **vendor mesh as shelved**.

### neck-plate — 2.0 x 20.0 x 11.0 mm, 0.55 g, 127 s
- Zero support, 11 layers, 200 mm2 of bed, all 4 x Ø2.30 up the build axis.
- 0.850 mm wall (p1 0.863) — just over two perimeters. Keep 2 perimeters.
- Smallest part in the set; print it with something else.

### yaw-roll-motion — 34.0 x 35.9 x 22.5 mm, 4.71 g, 933 s
- **The one part with a genuinely sub-two-perimeter wall**: exact 0.750 mm at
  (8.749, 8.021, 17.0), and p1 0.850 mm says it is local rather than pervasive.
  0.750 mm is 1.9 perimeters — the slicer will either thin the extrusion or
  drop a wall there. **Fix the model or accept a weak spot; do not print it and
  hope.**
- 207 mm2 support in -Z (113 layers).
- **10 bores across the layers**, including the **Ø12.00** — bridged and oval
  if it is a bearing seat.
- Slicer note: "sliced AS MODELLED - auto-orient (-100) crashed the slicer on
  this mesh". The gram figure is therefore for a different orientation than the
  one recommended here. Sliced from the **vendor mesh as shelved**.

---

## power-support — the full risk list

54.466 x 17.000 x 83.130 mm, PLA, **13.15 g / 2302 s sliced** (from OUR
rebuild, not a vendor mesh), 416 layers at 0.2 mm upright. `printability` = OK
(fits, wall exactly at the floor). This is the part the drawing has to carry,
and it has seven distinct print risks.

**1. Printed upright it balances on the latch tongue's tip — 10.64 mm2.**
MEASURED: in the +Z build the *entire* bed contact is **two facets**, x
-5.017..+5.017, y 25.000..26.060, at z = -26.186 — exactly the latch tongue's
`2 x TONGUE_HW x TONGUE_T = 10.034 x 1.060 mm` from `cad/part.py`. The next
material is **3.7 mm above the bed** (the plate bottom at z = -22.483, 59.6 mm2
of flat down-face). An 83 mm tall, 13 g part on a 10.6 mm2 foot will come off
the plate, and the foot is the one feature that must survive as a spring.
*This is the single most important note on the drawing.*

**2. There is no good orientation, only a choice of which problem to buy.**
All six measured, elevated `beta<30` area / bed contact:

| build dir | support mm2 | bed mm2 | height | layers |
|---|---|---|---|---|
| **+Z (upright)** | **969** | **10.6** | 83.1 | 416 |
| -Z (inverted) | 1027 | 0.9 | 83.1 | 416 |
| ±X (on edge) | 1710-1712 | 26.1 | 54.5 | 273 |
| -Y (back down) | 3190 | 249 | 17.0 | 85 |
| +Y (face down) | 3444 | 37 | 17.0 | 85 |

The farm's own rule for this part reads *"auto-orient: tall cradle laid on its
back to cut supports"* — and the measurement says laying it on its back
**triples** the support (969 → 3190 mm2), because the plate's back face is held
7 mm off the bed by the two mounting flanges and the whole 54 x 83 mm plate
then floats. It buys 24x the bed contact for 3.3x the support. Both numbers are
here; the drawing must state which was chosen and why. The slicer independently
flagged this part **"floating regions - enable supports"**.

**3. The head shelf is a 437 mm2 cantilevered ledge.** MEASURED by z band, +Z
build — where the 969 mm2 of support work actually is:

| z band (mm) | support mm2 | of which flat (beta<10) | what it is |
|---|---|---|---|
| 48 .. 54 | **437.0** | 428.2 | head shelf underside at z = 49.017, 46 mm wide x ~8 mm deep, out to y = 35, plus the two screw-pin legs and webs |
| 36 .. 42 | 151.8 | 148.7 | **upper mounting flange** underside at z = 40.73 (y 18..27) + gusset |
| 12 .. 18 | 153.6 | 153.6 | **lower mounting flange** underside at z = 14.33 + gusset |
| -18 .. -12 | 97.6 | 73.5 | rail bottom ends (z -16.75), cell lips (z -16.678), the latch slit tops (z -12.917) |
| -24 .. -18 | 68.3 | 59.6 | **the plate's own bottom edge** (z = -22.483) — floating 3.7 mm up, see risk 1 |
| 6 .. 12 | 19.9 | 8.5 | battery-face bosses / window lower edge (x ±11, y 25..29) |
| 24 .. 30 | 8.1 | 8.1 | upper cell lip underside (z 20.022, y 31.3..32.8) |
| 18 .. 24 | 5.7 | 5.7 | upper cell lip |
| 54 .. 60 | 12.5 | 4.7 | head top / notch |

None of these bridge between two walls — they are all one-sided ledges off the
plate. They need support, and support under the head shelf and both flanges
will leave witness marks on faces that mate with the trunk base and the banana
PCB locker.

**4. The 0.466 mm latch slits are narrower than one extrusion.**
`SLIT_W = 0.466` in `cad/part.py`. The two slits are the *only* thing separating
the sprung tongue from the plate — they run from z = -12.917 down through the
plate bottom. A 0.4 mm nozzle laying one line into a 0.466 mm gap leaves
0.066 mm of air, and gap-fill closes what it cannot fit a line into. **If the
slits fuse, the tongue is not a spring, it is part of the plate, and the
battery does not clip in.** This is a geometry problem, not a slicing one:
0.466 mm is a mesh-derived dimension copied from Pollen's decimated STL, and it
wants to be widened to at least one clean nozzle width (0.5-0.6 mm) before
anyone prints this. Verify with a slice preview before committing a plate.

**5. The sprung latch tongue is thin, cantilevered, moving — and it is also the
foot.** 10.034 mm wide x **1.060 mm thick** (2.6 perimeters), free length
13.27 mm from the slit top at z = -12.917 to the tip at z = -26.186, with five
R0.4 grip ridges and a hook that stands 5.31 mm proud (ramp y 26.0 → 31.31 over
z -26.186 → -22.1). Printed +Z the layer lines run **across** the bending axis,
so every flex works a layer bond: this is the delamination/fatigue candidate of
the whole robot. The hook's ramp face measures **35.5 deg to the plate** — above
the 30 deg threshold, so it needs no support, but it is in the 45 deg band and
will show stair-stepping on the ramp the battery slides over.

**6. Ten M2 tap holes, all across the layers.** MEASURED axes: **8 x Ø1.60 x 4.0
deep** on Y (the two stadium bosses, 4 each, for the battery-contact PCB) and
**2 x Ø1.55 x 7.8 deep** on Y (the Ø3.9 screw pins the banana PCB locker bolts
to). In the +Z build every one of them is horizontal: the top arc bridges, and
a Ø1.55 bore this small closes further on any FDM machine. `cad/part.py` calls
them tapping holes; in practice **drill to tapping size and form-tap after
printing, or use M2 heat-set inserts.** Do not expect a threadable hole off the
bed. (No shrinkage figure is quoted here because nothing in this repo has
measured one — the farm's printer is the authority.)

**7. The Ø2.50 flange holes are the only ones that print clean.** 4 hole
records on the **Z** axis in 2 coaxial groups (`of_group = 2`, span 28.34 mm) —
i.e. two bolt holes at x = ±9.5, y = 20.5, each passing through both 1.94 mm
flange lips at z = 15.3 and z = 41.7. In the +Z build they run up the build
axis: round, slightly undersize, no bridge. They mate with the trunk base's
Ø2.30 holes.

**8. Wall exactly at the floor, no margin.** Exact thinnest wall **0.800 mm** at
(-1.672, 26.217, -16.945) — precisely two 0.4 mm perimeters — and the rays
agree it is a real wall (min 0.7998, **p1 0.7998**, p5 1.175, median 2.000), not
a chamfer sliver. Any nozzle bigger than 0.4, or a slicer that drops to one
perimeter on thin features, and that wall is air. **0.4 mm nozzle, >= 2
perimeters, no exceptions.**

**Verdict: PRINTABLE-WITH-CARE**, and the two items that are model problems
rather than print problems — the **0.466 mm slit** and the **10.6 mm2 foot** —
should be resolved in CAD before this part is drawn for manufacture.

---

## The drawing note block

Every rebuilt part's sheet should carry the ones that apply to it.

1. **FDM, PLA, 0.4 mm nozzle, 0.2 mm layer, minimum 2 perimeters.** The
   two-perimeter floor is 0.80 mm and four parts sit at or under it
   (power-support 0.800, hip-bracket 0.800, neck-plate 0.850,
   **yaw-roll-motion 0.750 — under**).
2. **Build direction is a dimension.** State it on the sheet. It is not the
   part's Z: measured, the best direction is +Z on only 3 of 20 parts.
3. **A bore across the layers is not the bore you drew.** Its top arc bridges
   and it prints oval and undersize. **Ream after printing**: ankle Ø15/Ø14,
   hip-bracket and neck-pitch-bracket Ø6.00, yaw-roll-motion Ø12.00,
   shin Ø6.00/Ø5.50, upper-leg Ø5.37.
4. **Small tapped holes are not tapped by the printer.** Every Ø1.55 / Ø1.60
   (M2) — power-support x10, foot x1 — must be drilled to tapping size and
   form-tapped, or fitted with an M2 heat-set insert. No shrinkage allowance is
   given here because none has been measured on this farm.
5. **Support is required on 15 of 20 parts**, up to 969 mm2 (power-support) and
   870 mm2 (feet). Support witness marks land on mating faces — say on the sheet
   which face must stay clean.
6. **Brim the small-footed parts.** shin (3.6 mm2), power-support (10.6 mm2),
   foot L/R (43 mm2) do not hold the plate on their own.
7. **Thin plates lie flat.** rigidity-plate (1 mm, 5 layers), neck-plate (2 mm,
   11 layers), trunk-base and bearing-roll (3 mm, 15 layers). Standing them on
   edge is hundreds of layers of a single wall.
8. **A sub-0.80 mm reading is not automatically a thin wall.** Quote the exact
   figure with the ray p1 beside it, as this document does, or the note is
   noise.
9. **Machining: not applicable.** `machining.plan` returns CANNOT DETERMINE on
   all 20 because *"fdm is ADDITIVE"*. If a part is ever moved to a subtractive
   process it must be re-planned, not assumed.

---

## What is still NOT measured

- **Bridge vs. island.** Support area is an upper bound; nothing here tells a
  spanning bridge from a floating ledge.
- **Hole shrinkage.** No measurement of printed-vs-nominal bore diameter exists
  in this repo. That is why every note says "ream/tap", never "add 0.2 mm".
- **Warp, first-layer adhesion, TPU stringing.** Process, not geometry.
- **Non-axis-aligned orientations.** Only the six axis-aligned build directions
  were measured. A tilted orientation could beat all six and was not tried.
- **Twelve of the twenty were sliced from the VENDOR mesh, not our rebuild**
  (ankle L/R, foot L/R, hip-bracket, motor-support, neck-pitch-bracket,
  neck-plate, sole L/R, rigidity-plate, yaw-roll-motion): their grams and
  seconds are Pollen's mesh's, not ours. The other eight (banana-pcb-locker,
  bearing-roll, power-support, shin, trunk-base, upper-leg L/R, yaw2roll) were
  sliced from our own rebuild. The rebuilds match the reference to p95 <= 1 mm,
  but a matching part is not the same STL and the slicer read the other file.

## Reproduce

```sh
export CE_TRIAD_ROOT="$PWD:$(dirname $(dirname $PWD))"
ce-cad/bin/cad tools/dfm_rebuilt.py     # solid + mesh DFM  -> out/dfm/dfm-rebuilt.json
ce-cad/bin/cad tools/dfm_orient.py      # self-check, then the orientation block
ce-cad/bin/cad tools/dfm_rows.py        # the rows above + the power-support breakdown
python3 tools/dfm_verify_md.py          # read the table above BACK and check every cell
```

`tools/dfm_verify_md.py` re-parses the summary table the way a reader does and
re-derives all ten columns from `out/dfm/dfm-rebuilt.json` and
`out/print/slice.json`, including re-applying the verdict rule. It currently
reports **20 rows, reads back clean**. It was broken on purpose first, seven
ways, and bit on every one: a gram figure nudged, a support area nudged, a
build direction flipped, a layer count wrong, a thin wall laundered upward, a
verdict upgraded to PRINTABLE, and a whole row deleted.

`microduck-ankle-left` was re-measured on its own: in the 20-part run its
`export_stl` hit a full disk (FreeCAD's own cache failed to write in the same
second) and its mesh block was missing. Recorded in the JSON as `$rerun`.

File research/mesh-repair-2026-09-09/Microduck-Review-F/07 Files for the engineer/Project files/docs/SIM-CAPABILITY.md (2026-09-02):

# Simulation capability — measured against SolidWorks

Every number in section 1 marked **measured** was produced by running the tool on
this Mac (8-core, macOS) on 2026-09-02; **cited** numbers name the file or URL they
come from. Toolchain state as measured today: `cargo 1.97.1` on PATH; `gmsh` and
`ccx` NOT on PATH but found at runtime inside FreeCAD.app (proven working by the
passing FEA runs below); MuJoCo 3.12.0 + onnxruntime 1.29.0 in FreeCAD's python;
`MUJOCO_GL=glfw` offscreen rendering works. **Re-verified 2026-09-02** (section
3): the stress self-test, a mechanism sweep and the policy-in-the-loop round-trip
were each re-run; verdict counts and the walk trajectory reproduced exactly, and
the real-time-factor numbers were corrected downward after re-measurement (they
are load-dependent and the machine was at load average 28 — see §1.4 and §3).

## 1. Feature matrix — our stack vs the SolidWorks feature set

Column key: ce-cad = `~/dev/ce-workshop/ce-cad` (FreeCAD/OCC kernel, Python),
ce-struct = voxel FEA + CalculiX, ce-motion = torque/margin studies,
MuJoCo lane = `ce-designs/microduck/sim/`.

### 1.1 CAD core (SolidWorks Standard)

| SolidWorks feature | ours | evidence |
|---|---|---|
| Parametric solid modeling | YES, code-parametric (Python over the OCC kernel), no sketch UI | **measured**: `examples/nema_mount/design.py` — bracket + NEMA17 + 4 stock screws, build + 9-check verification in 5.3 s (6.8 s wall) |
| Assemblies with mates | YES — declared connectors, `mate()`/`fasten()`/`connect()`, standard interfaces (NEMA faces, ISO screws); a wrong-size mate is REFUSED with the number | **measured**: same nema_mount run prints per-bolt engagement (M3x10 through 6 mm, 4 mm engaged); joint models spec'd in `ce-cad/CLAUDE.md` §Connections |
| Engineering drawings | YES — third-angle views, sections, hole tables, title block, DXF+SVG, and every dimension is READ BACK against the solid | **measured**: `examples/blueprints/make.py` — 3 real parts to verified sheets in 57.0 s wall; 40/40 read-back checks agree with the solid |
| Interactive sketching / feature tree UI | NO — everything is a script; the browser viewer is view + transport + physics-poke only | by design; nearest equivalent is re-running the script (5–60 s, above) |
| Configurations / design tables | PARTIAL — parameters are Python variables; sweeps are shell loops; no configuration manager | `ce-struct` `--set bodies.0.material=PETG` style overrides exist per study |
| CAM / toolpaths | NO — `cecad/machining.py` + `dfm.py` judge manufacturability and cost, they do not emit G-code. 3D-print plating exists (cad-print skill) | cited: `ce-cad/CLAUDE.md` §Manufacturing, §DFM |
| PDM / versioning | PARTIAL — git + a published catalog; known gap: nothing auto-retracts a stale catalog entry | cited: `ce-cad/CLAUDE.md` §KNOWN BROKEN (19 stale `atech_actuator_*` entries measured 2026-08-13) |
| Electrical/PCB | YES beyond SolidWorks Standard — `cecad/electrical.py`, `pins.py`, `pcb.py`, voltage drop over the measured loom | cited: `ce-cad/CLAUDE.md` §Electrical/§PCB |

### 1.2 Motion (SolidWorks Motion)

| SolidWorks Motion does | ours | evidence |
|---|---|---|
| Kinematic mechanism solve | YES — Newton on C(q)=0 from the assembly's own declared joints, verified against closed forms only (never solver-vs-solver) | **measured**: `cecad.physics.self_test()` 28 checks ALL PASSED, 23.5 s wall; scotch yoke vs x=r·cos t to 4.6e-14 mm; leadscrew vs lead/360·turns to 0.0 mm |
| Rigid-body dynamics (forces, springs, gravity) | PARTIAL — ONE integrated coordinate (the driver); springs/gravity/stops reflected through the real mechanism; mass/COM/inertia measured off the solids; a doc with no measured inertia REFUSES to tick | **measured**: `tests/test_dynamics.py` 11/11 passed (69.3 s wall incl. builds); pendulum period to 0.18% of 2π√(J/mgd) (cited, CLAUDE.md §97) |
| Real-time interactive dynamics | YES, and SolidWorks does not have this — the Rust kernel (`kernel/src/dynamics.rs`) ticks live in the viewer and from Python | **measured**: 10.05 µs/tick over 10,000 ticks on `rotary_pointer.mech.json` = 99.5x real time at dt=1 ms; viewer live solve worst 0.17 ms/frame (cited, CLAUDE.md §96) |
| 3D contact between bodies | NO contact solver — a pin leaves its slot by declared `pin_slot`/`dwell_lock` regimes, not by collision response. MuJoCo covers this (below) | cited: CLAUDE.md §97 "no contact solver"; §pin_slot |
| Friction | NO — viscous `damping` only, no Coulomb friction | cited: CLAUDE.md §97 |
| Spatial (3D) linkages solved live | PARTIAL — planar mechanisms solve live; trains and spatial linkages fall back to the baked (pre-checked) track, and the transport badge says which you are watching | cited: CLAUDE.md §96 |
| Event-based motion, motor curves | PARTIAL — motor torque is a DECLARED number (`motion={"torque_Nmm": ...}`); deriving it from chip data is an open item. ce-motion does torque budgets/actuator margins from part-folder facts | cited: CLAUDE.md §97; `ce-motion/README.md` |
| Full mechanism audit | YES — `bin/connections`, collision sweep, mobility, loop closure; refusals are verdicts | **measured**: `examples/kinetic_totem/motion.py --quick` 81.4 s wall — 17 checks passed, 1 CANNOT DETERMINE (the example declares no keep-out zones, so keepout refuses rather than passes; the parent gate correctly BLOCKS on it) |

### 1.3 FEA (SolidWorks Simulation Standard/Professional/Premium)

| SolidWorks study | ours | evidence |
|---|---|---|
| Linear static | YES, twice, in two independent codebases that cross-check: ce-cad (gmsh quadratic tets + CalculiX) and ce-struct (own hex8 voxel solver + CalculiX) | **measured**: `cecad.stress.self_test()` 26/26 in 13.3 s (tension bar 99.999 vs 100.000 MPa closed form); `ce-struct bin/struct bracket` 7,080 cells, PASS SF 5.74, 1.57 s wall. Cited: the two lanes agree on stiffness to 0.052%, differ 13.9% on singular peak stress (ce-cad CLAUDE.md §Stress, measured 2026-08-30) |
| Frequency (modal) | YES — ce-struct modal study via CalculiX | cited: proven vs cantilever f₁ to 0.40%, mode ratio 0.33% (`ce-struct/README.md`, part of the 612-check `npm test`, measured 2026-08-30) |
| Buckling | YES — ce-struct via CalculiX | **measured**: `bin/struct bracket --study buckle` PASS, folds at 108.71x, 6.0 s wall; cited: Euler closed form to 0.41% |
| Nonlinear (plasticity, large deformation) | YES in ce-struct only — yield study with hardening curve + NLGEOM; ce-cad's lane is strictly linear/static/isotropic/one-part | cited: hardening curve reproduced to 0.00%; NLGEOM changes plastic strain 3.5x on the necking bar (`ce-struct/README.md`) |
| Contact | PARTIAL — ce-struct's contact study (separation/sliding via CalculiX, proven to 0.06% + zero-tension check); ce-cad has none | cited: `ce-struct/README.md` five studies table |
| Thermal | NO — CalculiX can, nothing here drives it | gap |
| Fatigue | NO | gap |
| Drop test / explicit dynamics | NO — OpenRadioss is named in ce-struct's survey, not wired | gap; cited `ce-struct/README.md` |
| CFD (Flow Simulation) | NO (ce-fluid exists in the workshop but is not part of this measured lane) | gap |
| Linear dynamic (transient/harmonic/random vibration) | NO | gap |
| Multi-part assembly FEA | NO in ce-cad (one part at a time); ce-struct takes multi-body studies with contact | cited: ce-cad CLAUDE.md §Stress "What it is NOT" |
| Printed-material anisotropy | AHEAD of SolidWorks defaults — ce-struct REQUIRES `printNormal`, transversely isotropic deformation + separate failure allowables; refuses a guess | cited: `ce-struct/README.md` §Materials |

SolidWorks study list used for comparison: [GoEngineer package comparison](https://www.goengineer.com/blog/comparing-all-solidworks-simulation-packages-basic-to-advanced), [MLC-CAD study-type overview](https://www.mlc-cad.com/resources/solidworks/overview-of-solidworks-simulation-study-types/), [solidworks.com Simulation](https://www.solidworks.com/product/solidworks-simulation).

### 1.4 What actually runs in real time (SolidWorks: nothing in this class)

Real-time factors here are **machine-load dependent** and every row below marked
*re-measured 2026-09-02* was taken while this 8-core Mac carried **load average
27.95** (≈3.5x oversubscribed — other agents' FreeCAD/MuJoCo processes running),
so they are **lower bounds**, not the machine's ceiling. The one number that is
**invariant of load** is the trajectory: the 10 s walk lands at **1.0045 m,
did not fall, max tilt 4.11°** on every run (bit-exact, three runs).

| lane | measured rate | real-time factor |
|---|---|---|
| Rust kernel live tick (single mechanism, 1 coordinate) | 10.05 µs/tick (10,000-tick bench, cited CLAUDE.md §96) | **99.5x** real time at dt=1 ms; also runs as wasm in the browser viewer |
| Viewer live kinematic solve | worst 0.17 ms/frame over 241 frames, 8 machines (cited, CLAUDE.md §96) | comfortably 60 fps |
| MuJoCo `mj_step`, microduck standing (ncon=5, dt=5 ms, contacts on) | **re-measured 2026-09-02**: 227 µs/step (4,000-step bench, under load 28) | **22x** real time under load; a quiet machine did 33.8 µs/step = 148x (cited, prior bench) |
| ONNX walking policy inference alone | **re-measured 2026-09-02**: 122 µs/inference (2,000-call bench, under load 28) | negligible vs the 20 ms control period |
| MuJoCo + ONNX policy at 50 Hz (the real control stack's loop shape) | **re-measured 2026-09-02**: 10 s walk in **0.61–0.77 s** steady-state loop wall (best 0.607 s; 2.71 s cold, first process); walked 1.0045 m at vx 0.25, did not fall | **13–16x** real time under load (best 16.5x); the earlier **0.13 s / 77x** was the *theoretical sum* of per-part costs (122 µs policy + 4×33.8 µs `mj_step`) × 500 steps = 0.128 s, **not** a measured full-loop wall, and did not reproduce — the loop's Python obs/apply/record overhead is real. It is comfortably faster than real time either way. |
| ce-struct in-tab static solve | 1.57 s for 7,080 cells (re-solves while a slider moves) | interactive, not real-time physics |

### 1.5 Testing microduck's REAL software against simulation (the Isaac Sim question)

| layer | state today | evidence |
|---|---|---|
| The shipped ONNX policies in physics | YES — `sim/run_policy.py` reproduces the 50 Hz obs/action loop of `infer_policy.py` and the browser sim, on Pollen's MJCF with OUR meshes swapped in (collision geoms + inertials stay stock, qpos verified bit-identical stock-vs-ours) | **measured**: `out/sim/report.md` — 9 standard runs; walk 0.79 m/8 s at vx 0.25; stand-still band ends between 0.20 and 0.25 m/s |
| The real Rust daemons (robotd et al.) in the loop | NO physics-in-the-loop bridge exists. What exists: `duck-control`'s `RobotIo` trait with a `FakeIo` backend (`--fake`) — the daemon runs without hardware, against CANNED sensors, not simulated dynamics | read from the clone: `duck-control/src/io.rs` (`pub trait RobotIo`, `FakeIo`, "simulated failure" error) |
| The robot's kinematics code vs physics ground truth | YES — Pollen's own Rust FK crate is tested against MuJoCo's `mj_kinematics` on 64 random poses to 1e-6 m | read: `kinematics/tests/fk_against_mujoco.rs` |
| What a robotd↔MuJoCo bridge would need | a `RobotIo` impl that answers `sync_read` (15 servos + the id-200 IMU register block) from `mj_step` state and applies goal positions as `data.ctrl` — the trait seam already exists; the work is the Dynamixel register model + real-time pacing | gap, not measured |
| Isaac Sim's actual add | GPU-parallel RL at scale (thousands of concurrent envs), RTX sensor simulation (camera/depth/lidar/radar, segmentation, synthetic data), USD scenes, ROS 2 integration | cited: [NVIDIA Isaac Sim paper (arXiv 2606.03551)](https://arxiv.org/html/2606.03551v1), [Isaac Lab](https://github.com/isaac-sim/IsaacLab), [NVIDIA/HF state of simulation](https://huggingface.co/blog/nvidia/state-of-simulation-for-physical-ai). None of that is needed to RUN Pollen's already-trained policies (re-measured above at 13–16x real time on this CPU under heavy load — comfortably faster than real time); it becomes relevant if we TRAIN policies or need camera/lidar sensor realism |

## 2. Is it like SolidWorks?

No — it is not feature-parity with SolidWorks, and it is not trying to be the
same shape of tool. Where we are behind: there is no interactive sketch/feature
UI at all (every part is a script and a rebuild costs 5–60 s, measured above);
motion has no contact solver, no Coulomb friction, and integrates one coordinate,
where SolidWorks Motion does full 3D rigid-body contact; FEA has no thermal,
fatigue, drop-test, linear-dynamic or CFD lane, and ce-cad's own FEA is
linear-static one-part-at-a-time (nonlinear plasticity, buckling, modal and
contact live only in ce-struct); there is no CAM and no real PDM. Where we are
ahead of SolidWorks: everything is scriptable and git-diffable, so an agent can
build, verify and sweep designs unattended; evidence discipline — every solver is
proven against closed forms it did not compute, drawings are read back against
the solid (40/40 checks, measured), and a missing fact is a named CANNOT
DETERMINE rather than a silent pass (the totem run above blocks its own gate for
an undeclared keep-out); real-time — the Rust kernel ticks a live mechanism at
~100x real time and MuJoCo runs the microduck's actual shipped ONNX policies with
full contact faster than real time on this 8-core CPU (re-measured 13–16x today
under a load average of 28; the bit-exact 1.0045 m walk trajectory is invariant
of load), a software-in-the-loop lane SolidWorks simply does not have. On the Isaac Sim question: we already do
the part of Isaac Sim that matters for microduck today — physics-accurate
policy-in-the-loop simulation on our own rebuilt geometry — but only at the
policy level; the real Rust daemons (robotd) can run hardware-free against a
FakeIo stub, not against physics, and closing that gap is a bounded piece of work
(a `RobotIo` impl backed by `mj_step`), while Isaac Sim's genuine additions —
GPU-parallel training, RTX camera/lidar rendering, ROS 2 — are things nothing in
this stack provides.

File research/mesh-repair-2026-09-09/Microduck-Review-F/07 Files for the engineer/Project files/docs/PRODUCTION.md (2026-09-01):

# PRODUCTION — what it costs and what it takes to build a Microduck at 1 / 10 / 100 / 1,000 units

*Synthesised 2026-09-02 from three research lenses written the same night —
`production/components.md` (bought parts, vendor pages read 2026-09-02),
`production/process.md` (print vs mould, web sources read 2026-09-02) and
`production/compliance-and-assembly.md` (battery shipping, CE/FCC, packaging,
labour; read 2026-09-02, Pollen store JSON 2026-09-01). Nothing was built,
sliced or quoted; this machine was under load and only the web was used.
Every number below carries a source ID; the ID → URL → date-read table is §8.
A number no source stated is **CANNOT DETERMINE** with what settles it.
Reference price: Pollen sells the assembled robot with gamepad, battery and
USB-C cable for **$399 / €340** [S1].*

## 0. The one-paragraph answer

Bought parts whose price was actually read come to **$472–481 per robot in
USD** (plus ≈ NZD 65 of bearings and ≈ €8.5 of screws) at every quantity from
1 to 1,000, because the only line with real weight — 15 × Dynamixel
XL330-M288-T at $23.90 = **$358.50, 75 % of the total** — has no published
volume tier anywhere [C1][C2]. That subtotal already exceeds Pollen's $399
retail before the Radxa board, speaker, mics, NFC, three custom PCBs, filament,
assembly, packaging, certification or margin. So the whole volume question for
this robot reduces to one quote (ROBOTIS OEM pricing for XL330 at 1,500 and
15,000 units) and one process decision (mould the 9 visible shells at 1,000
units, keep the 22 small brackets printed). Assembly is 36–101 minutes of
attended labour per unit by a Boothroyd-Dewhurst count, i.e. 14–40 CNY at
the Shenzhen minimum wage or $24–67 at a burdened North-American rate
[S43][S44][S46]. Pollen's own manufacturing is at Seeed Studio in Shenzhen
against a > 20,000-unit target [BB]; its only word about process is "printed"
[PK].

## 1. Executive table — cost per robot at 1 / 10 / 100 / 1,000

Rules: a cell is a number only where every input was read from a source; a
bracket "[a–b]" is arithmetic on sourced rates and our own solid volumes or
counts, not a quote; "CD" = CANNOT DETERMINE, with the settling step in §5.
Currencies are the vendor's; no FX rate was fetched.

| line | 1 robot | 10 robots | 100 robots | 1,000 robots | what is in it / what settles the CD |
|---|---|---|---|---|---|
| **Bought, exact parts read (USD)** [C-roll] | **$481.21** | **$477.35** | **$472.64** | **$472.48** | XL330 ×15 $358.50 (no tiers) [C1]; X3P cables ×16 $24.80 [C3]; NP-F550 + charger share $24.95 [C5]; IMX219 B0183 + 75° lens $23.99 (sale price) [C7]; ToF breakout Pololu #3419 $24.95 → $19.43 @100+ [C10]; TLV320AIC3104 LCSC $2.25 → $1.23 @1000 [C13]; MR6700 bearings ×3 $14.58 → $12.39 [C17]; M2 inserts ×60 $7.19 [C20] |
| Bought, native-currency lines read | NZD 64.90 + GST; €8.46 | same | same | bearings: US$11–44 (factory, MOQ 1,000 pcs) [C16]; €8.46 | 22×16×4 MR1622-ZZ ×11 at NZD 5.90 [C15]; 195 M2 screws priced as M2×6 at €4.34/100 [C19] |
| Bought, bracket / substitute only (kept out of the subtotal) | $23–51 Radxa; $9.78 speaker | $23–51; $7.52 | $23–51; $6.08 | $23–51; $4.98 | Radxa: the 1 GB/32 GB SKU **does not exist** in Radxa's SKU table; nearest 1 GB/8 GB $23 or 4 GB/32 GB $51, all sold out 2026-09-02 [C4]. Speaker: nearest catalogued 2 W 39×20 part SPM-2035NU, not the 35×25 mesh [C14] |
| Bought, unpriced | CD | CD | CD | CD | Radxa (see above); CSI flex; mic(s); NFC IC + 2 antennas; REC LED; gamepad; USB-C cable; PCBs P1 Robot HAT / P2 `imu_to_dxl` / P3 banana (no design files exist — must be designed); LSM6DSV16X, BMI088, transceiver, MCU; filament [C-13] |
| **Printed hard parts** (24 slugs, 31 pieces, ≈ 198 cm³ solid) [PR-2] | FDM in-house: material ≤ $6.5 [PR-3]; machine h × $0.10–0.31 [LM1][CC]; labour ≤ $155 if 31 pieces are handled one at a time (15 min @ $20 each) [CC]; **hours CD (not sliced)** | same per robot; one printer | FDM farm: $2–4 per print-hour [LM2][PR2] × Σh **CD**; ≈ 41 printer-days per 100 robots at 76 parts/printer-day [PR2]; MJF floor ≈ €57 grey / €83 smoothed per robot on solid volume [HP] | mould the 9 visible parts: tooling $13,455 (Protolabs floor) – $90,000 (aluminium bracket) → **$13–90 per robot** + moulded parts $4.50–45 [PL1][HT]; 22 brackets stay FDM (hours CD) | grams and hours per piece need `cad-print` / ce-slice on the rebuilt parts; quotes need the STEP export (GOAL rung 6) |
| **Soft parts** (4 pieces, ≈ 34 cm³) [PR-2] | FDM TPU material ≤ $2 [LM3] | same | MJF TPU 90A ≈ €20 per robot [HP]; urethane casting 20–30 pulls per $500–3,000 mould [ML] is worse than printing | TPU injection: 3–4 tools ≥ $4,485 → ≥ $4.50 per robot + parts [PL1] | durometer and material of Pollen's lips CD |
| **Assembly labour** (36–101 min attended) [K-7] | 14–40 CNY @ Shenzhen 23.7 CNY/h [S46]; $24–67 @ $40/h burdened [S44]; €7.4–20.7 @ SMIC gross [S45] | same | same | same | no learning-curve source was read; the 120 → 206 screw count is 17.5 min of the spread; heat-set inserts (0 or 60) another 10 min |
| **Servo ID / EEPROM + image + test** | 10–26 min inside the 36–101 above [K-7] | same | same | same | whether ROBOTIS ships servos pre-ID'd is CD (`model.rs:84`, `bus.rs:128` say the runtime corrects them) |
| **Packaging** | CD | CD | CD | CD | no box price read; constraints known (§3.3): rigid box passing stacking (PI 967 II) and 1.2 m drop if spares packed (PI 966 II) [S9][S10]; insert must prevent activation — the robot has no power switch [S9 E.08]; Pollen ships 1,200 g per robot box [S1] |
| **Certification / test lab** | CD | CD | CD | CD | no lab quote read; obligations in §3 |
| **Total** | **CD** — floor **≥ $481 + NZD 65 + €8.5 + material + labour** before any unpriced line | CD | CD | CD | the floor already exceeds $399 [S1]; the gap is the ROBOTIS OEM price |

Reading across: between 1 and 1,000 robots every *read* bought line together
moves by less than $9 [C-roll]; the material bound on the printed set is
≤ $8.5 per robot; the visible-part moulding decision adds $13–90 per robot of
tooling at 1,000 units and removes an unknown number of print-hours. Nothing
read makes a 1,000-unit robot cheaper than a 1-unit robot by more than about
$10 unless the servo price moves.

## 2. Make / buy and print / mould
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

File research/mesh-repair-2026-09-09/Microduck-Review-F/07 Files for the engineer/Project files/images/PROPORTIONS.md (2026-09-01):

# Microduck — dimensional estimate

**Authority ranking:** (1) the MuJoCo model shipped in `pollen-robotics/microduck_rl` (`src/mjlab_microduck/robot/microduck/robot_walk.xml` + STL assets, exported with onshape-to-robot from Onshape doc `804927696f06d877f3f1803e`) — downloaded to `../cad/`; (2) published spec sheet (press kit); (3) photo measurement. The MJCF is the *alpha* CAD (it contains a Raspberry Pi Zero 2 W 65x30 board where production has an RK3566 board of the same Pi-Zero footprint, and an "np_f970" battery mesh that is actually NP-F550 sized: 38.6 x 20.6 x 70.8 mm), but every shell, leg, foot and head mesh matches the launch photos, so treat it as ground truth for geometry.

## Published
- Height 25 cm; width 14 cm; weight < 800 g (store lists 780 g); 15 motors; battery NP-F550 2600 mAh (press kit, store).
- Model total mass in MJCF: 737 g (trunk 199 g, head assembly 189 g, each thigh 48 g, shin 22 g, foot 30 g, yaw/roll blocks 23 g + 6 g).

## Kinematics (from MJCF; z = height above floor with trunk origin at 120 mm, all joints zero; mm)
| joint | position (x fwd, y left, z up) | axis | range |
|---|---|---|---|
| hip yaw L/R | (6, ±17.5, 115) | z | -25..+30 deg |
| hip roll L/R | (22.5, ±17.5, 102.5) | x | ±22 deg |
| hip pitch L/R | (4, ±42.5, 102.5) | y | ±90 |
| knee L/R | (-31.8, ±38.5, 80.5) | y | ±90 |
| ankle L/R | (-31.8, ±64.5, 38.5) | y | ±90 |
| neck pitch | (26, 14.5, 152.4) | y | -90..+60 |
| head pitch | (26, 14.5, 202.4) | y | ±90 |
| head yaw | (26, 0, 221.1) | z | ±170 |
| head roll | (8.1, 0, 235.6) | x | ±25 |
| jaw | closed-loop linkage off head (15th motor) | | |

Derived link lengths (perpendicular distance between parallel axes):
- **Thigh (hip pitch -> knee): 42.0 mm**; **shin (knee -> ankle): 42.0 mm**; ankle axis to sole bottom: ~36 mm; hip yaw to hip roll: 12.5 mm; hip roll to hip pitch: 25 mm lateral offset.
- Hip pitch spacing (stance width at hips): 85 mm; ankle spacing: 129 mm (legs splay outward ~26 mm per side through the knee offset, hence the wide-track duck stance).
- Neck: trunk -> neck-pitch 32 mm; neck link 50 mm; head-pitch -> head-yaw 19 mm; head-yaw -> head-roll 15 mm.
- Standing pose (`STAND` keyframe): hip pitch 26.2 deg, knee ~0, ankle 26 deg, neck pitch 20 deg, head pitch 20 deg. Sitting pose lowers trunk origin to 70 mm.
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

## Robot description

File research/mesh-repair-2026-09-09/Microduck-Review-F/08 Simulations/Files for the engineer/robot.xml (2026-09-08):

<mujoco model="microduck">
  <compiler angle="radian" meshdir="." autolimits="true" />
  <default>
    <default class="microduck">
      <joint frictionloss="0.1" armature="0.005" />
      <position kp="50" dampratio="1" />
      <default class="visual">
        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
      </default>
      <default class="collision">
        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
      </default>
    </default>
  </default>
  
  <default>
    <default class="perfect_actuator">
      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
      <joint damping="0.15" frictionloss="0.1" armature="0.001" />
      <position kp="10.0" kv="0.1" forcerange="-20.0 20.0" />
    </default>
    <default class="chosen_actuator_old">
      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
      <joint damping="0.048" frictionloss="0.006" armature="0.002" />
      <position kp="0.52" kv="0.0" forcerange="-0.91 0.91" ctrlrange="-10.0 10.0" />
    </default>
    <default class="chosen_actuator_new">
      
      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
      <joint damping="0.041" frictionloss="0.032" armature="0.002" />
      <position kp="0.386" kv="0.0" forcerange="-0.67 0.67" ctrlrange="-10.0 10.0" />
    </default>
    <default class="chosen_actuator_antoine">
      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
      <joint damping="0.044" frictionloss="0.013" armature="0.0017" />
      <position kp="0.43" kv="0.0" forcerange="-0.75 0.75" ctrlrange="-10.0 10.0" />
    </default>
    <default class="chosen_actuator">
      
      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
      <joint damping="0.053" frictionloss="0.0048" armature="0.0018" />
      
      <position kp="0.55" kv="0.0" forcerange="-0.96 0.96" ctrlrange="-10.0 10.0" />
      
      
    </default>
    <default class="passive_wheel">
      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
      <joint damping="0.0" frictionloss="0.0" armature="0.0001" />
    </default>
    <default class="passive_joint">
      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
      <joint damping="0.0" frictionloss="0.0" armature="0.0001" />
    </default>
  </default>
  
  <sensor>
    <framequat name="orientation" objtype="site" noise="0.001" objname="imu" />
    <gyro name="angular-velocity" site="imu" noise="0.005" />
    <gyro name="imu_ang_vel" site="imu" />
    <velocimeter name="imu_lin_vel" site="imu" />
    <accelerometer name="imu_accel" site="imu" />
    <subtreeangmom name="root_angmom" body="trunk_base" />
  </sensor>
  
  <default>
    <default class="self_collision_only">
      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
    </default>
    <equality solref="0.002 1" solimp="0.99 0.999 0.0005 0.5 2" />
  </default>
  
  
  
  
  
  
  
  <worldbody>
    
    <body name="trunk_base" pos="0 0 0.12" quat="1 0 0 0" childclass="microduck">
      <freejoint name="trunk_base_freejoint" />
      <inertial pos="-0.0226332 -2.70828e-05 0.00280064" mass="0.199224" fullinertia="0.000123975 0.000145931 0.000115351 7.1651e-08 -2.06915e-05 1.32429e-07" />
      
      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
      
      <body name="yaw2roll" pos="0.006 0.0175 -0.005" quat="0 -0.707107 -0.707107 -0">
        
        <joint axis="0 0 1" name="left_hip_yaw" type="hinge" range="-0.4363323129985824 0.5235987755982988" class="chosen_actuator" />
        <inertial pos="-8.8e-11 0.00099414 0.0168917" mass="0.0230406" fullinertia="4.1964e-06 3.41752e-06 2.3265e-06 -0 -0 -5.0881e-08" />
        
        <body name="hip_l" pos="0 0.0165 0.0125" quat="0.707107 -0.707107 -0 -0">
          
          <joint axis="0 0 1" name="left_hip_roll" type="hinge" range="-0.3839724354387525 0.3839724354387525" class="chosen_actuator" />
          <inertial pos="0.014815 1.6179e-08 -0.00829992" mass="0.00618934" fullinertia="8.60626e-07 1.15753e-06 6.51588e-07 1e-12 3.89882e-07 -1e-12" />
          
          <body name="upper_leg_left" pos="0.025 0 -0.0185" quat="0.5 -0.5 0.5 -0.5">
            
            <joint axis="0 0 1" name="left_hip_pitch" type="hinge" range="-1.570796326795005 1.5707963267947882" class="chosen_actuator" />
            <inertial pos="0.006766 0.0228838 0.0134531" mass="0.0482067" fullinertia="1.68753e-05 1.03691e-05 1.98269e-05 -4.41852e-06 2.27982e-07 3.89298e-07" />
            
            <body name="leg" pos="0.022 0.0357771 -0.004" quat="0 0.707107 0.707107 0">
              
              <joint axis="0 0 1" name="left_knee" type="hinge" range="-1.570796326795012 1.570796326794781" class="chosen_actuator" />
              <inertial pos="-1.52e-10 0.0318937 -0.00953505" mass="0.0215844" fullinertia="5.25056e-06 2.15507e-06 4.33925e-06 -1e-12 0 7.65005e-07" />
              
              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
              
              <body name="ankle_left" pos="0 0.042 -0.026" quat="0 1 -0 0">
                
                <joint axis="0 0 1" name="left_ankle" type="hinge" range="-1.5707963267949019 1.5707963267948912" class="chosen_actuator" />
                <inertial pos="-0.00615738 -0.0137483 -0.0156586" mass="0.0300246" fullinertia="5.91525e-06 1.11534e-05 7.74015e-06 -2.0535e-07 8.2152e-08 5.6714e-08" />
                
                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</body>
            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</body>
          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</body>
        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</body>
      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</body>
      
      <body name="neck" pos="0.026 0.0145 0.0324215" quat="0 0 0.707107 -0.707107">
        
        <joint axis="0 0 1" name="neck_pitch" type="hinge" range="-1.5707963267948966 1.0471975511965976" class="chosen_actuator" />
        <inertial pos="0 -0.025 0.0141665" mass="0.0368414" fullinertia="1.72925e-05 3.12694e-06 1.63707e-05 0 0 0" />
        
        <body name="neck_pitch" pos="0 -0.05 -0" quat="0 1 0 0">
          
          <joint axis="0 0 1" name="head_pitch" type="hinge" range="-1.5707963267948974 1.5707963267948957" class="chosen_actuator" />
          <inertial pos="-6.533e-09 0.0116641 -0.0145" mass="0.00572" fullinertia="1.09186e-06 9.66855e-07 5.12111e-07 0 0 0" />
          
          <body name="yaw_roll_motion" pos="-0 0.0186931 -0.0145" quat="0 0 -0.707107 -0.707107">
            
            <joint axis="0 0 1" name="head_yaw" type="hinge" range="-2.967059728390373 2.967059728390348" class="chosen_actuator" />
            <inertial pos="-0.000166657 -0.00500964 0.0178065" mass="0.0486" fullinertia="6.97903e-06 8.10293e-06 9.57884e-06 3.21657e-07 -3.4797e-08 3.4295e-07" />
            
            <body name="jaw_soft" pos="-0.0179 0 0.0145" quat="0.707107 -0 -0.707107 -0">
              
              <joint axis="0 0 1" name="head_roll" type="hinge" range="-0.43633231299859127 0.4363323129985735" class="chosen_actuator" />
              <inertial pos="0.00460523 0.00120047 -0.0324761" mass="0.188766" fullinertia="0.000320812 0.0002541 0.000149882 -6.32292e-07 6.57154e-06 4.18476e-06" />
              
              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
              <camera name="head_camera" pos="0.0155 -9.13778e-05 -0.0733" quat="0 0 -1 0" />
              
              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</body>
          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</body>
        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</body>
      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</body>
      
      <body name="bearing_roll" pos="0.006 -0.0175 -0.005" quat="0 0.707107 0.707107 0">
        
        <joint axis="0 0 1" name="right_hip_yaw" type="hinge" range="-0.5235987755982988 0.4363323129985824" class="chosen_actuator" />
        <inertial pos="-8.8e-11 0.00099414 0.0168917" mass="0.0230406" fullinertia="4.1964e-06 3.41752e-06 2.3265e-06 -0 -0 -5.0881e-08" />
        
        <body name="hip_l_2" pos="-0 0.0165 0.0125" quat="0 -0 0.707107 0.707107">
          
          <joint axis="0 0 1" name="right_hip_roll" type="hinge" range="-0.3839724354387525 0.3839724354387525" class="chosen_actuator" />
          <inertial pos="0.014815 1.6212e-08 -0.00829992" mass="0.00618934" fullinertia="8.60626e-07 1.15753e-06 6.51588e-07 1e-12 3.89882e-07 -1e-12" />
          
          <body name="upper_leg_right" pos="0.025 0 -0.0185" quat="0.5 -0.5 0.5 -0.5">
            
            <joint axis="0 0 1" name="right_hip_pitch" type="hinge" range="-1.5707963267949268 1.5707963267948664" class="chosen_actuator" />
            <inertial pos="-0.006766 0.0228838 0.0134531" mass="0.0482067" fullinertia="1.68753e-05 1.03691e-05 1.98269e-05 4.41852e-06 -2.27982e-07 3.89298e-07" />
            
            <body name="leg_2" pos="-0.022 0.0357771 -0.004" quat="0 1 -0 -0">
              
              <joint axis="0 0 1" name="right_knee" type="hinge" range="-1.570796326794932 1.570796326794861" class="chosen_actuator" />
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

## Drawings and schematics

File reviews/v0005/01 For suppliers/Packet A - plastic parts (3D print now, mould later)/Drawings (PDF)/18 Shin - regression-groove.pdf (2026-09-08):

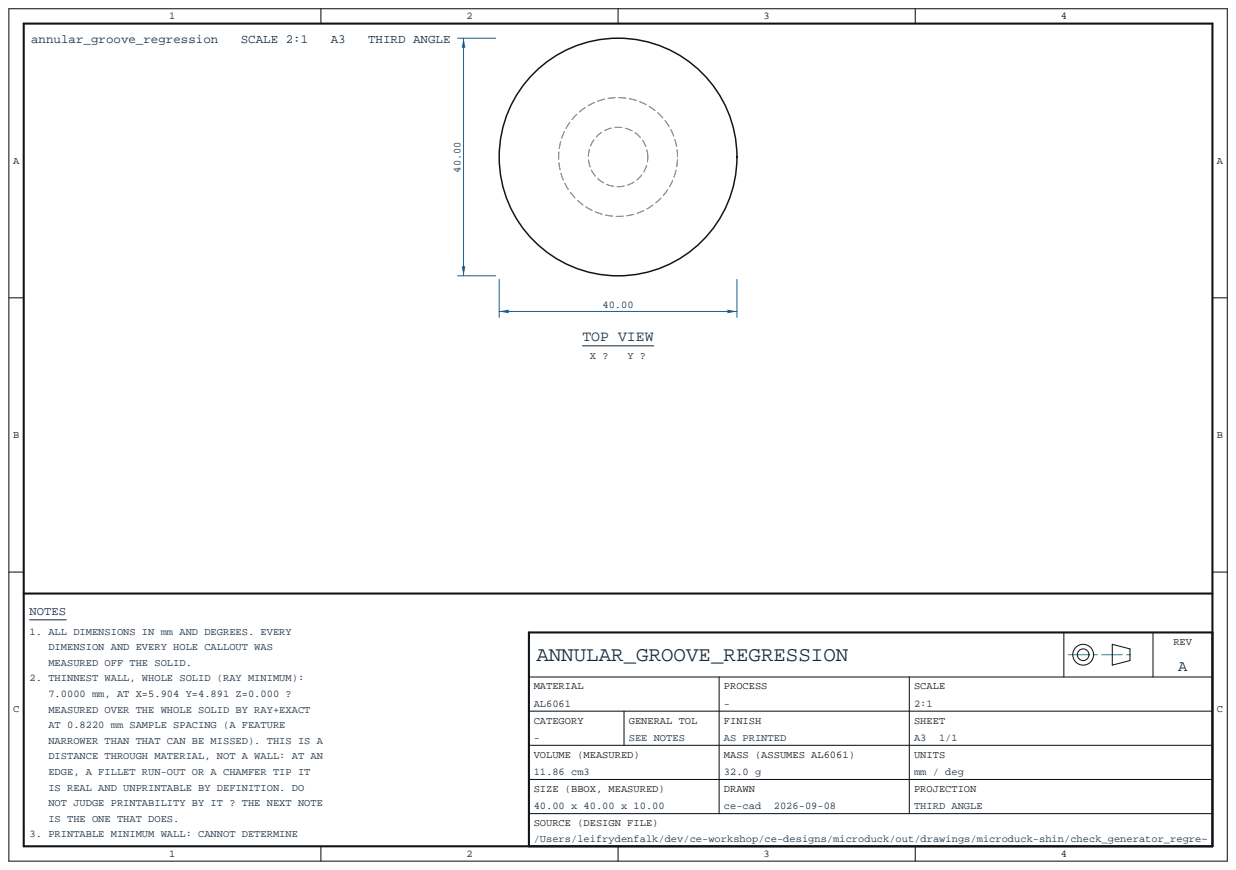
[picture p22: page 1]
TOP VIEW; NOTES; annular_groove_regression; SCALE 2:1; THIRD ANGLE

1. ALL DIMENSIONS IN mm AND DEGREES. EVERY
DIMENSION AND EVERY HOLE CALLOUT WAS
MEASURED OFF THE SOLID.
2. THINNEST WALL, WHOLE SOLID (RAY MINIMUM):
MEASURED OVER THE WHOLE SOLID BY RAY+EXACT
AT 0.8220 mm SAMPLE SPACING (A FEATURE
NARROWER THAN THAT CAN BE MISSED). THIS IS A
DISTANCE THROUGH MATERIAL, NOT A WALL: AT AN
EDGE, A FILLET RUN-OUT OR A CHAMFER TIP IT
IS REAL AND UNPRINTABLE BY DEFINITION. DO
NOT JUDGE PRINTABILITY BY IT ? THE NEXT NOTE
IS THE ONE THAT DOES.
3. PRINTABLE MINIMUM WALL: CANNOT DETERMINE

ANNULAR_GROOVE_REGRESSION | | | | REV A

MATERIAL AL6061 | PROCESS - | SCALE 2:1

CATEGORY - | GENERAL TOL SEE NOTES | FINISH AS PRINTED | SHEET A3 1/1

VOLUME (MEASURED) 11.86 cm3 | | MASS (ASSUMES AL6061) 32.0 g | UNITS mm / deg

SIZE (BBOX, MEASURED) 40.00 x 40.00 x 10.00 | | DRAWN ce-cad 2026-09-08 | PROJECTION THIRD ANGLE

SOURCE (DESIGN FILE)
/Users/leifrydenfalk/dev/ce-workshop/ce-designs/microduck/out/drawings/microduck-shin/check_generator_regre~

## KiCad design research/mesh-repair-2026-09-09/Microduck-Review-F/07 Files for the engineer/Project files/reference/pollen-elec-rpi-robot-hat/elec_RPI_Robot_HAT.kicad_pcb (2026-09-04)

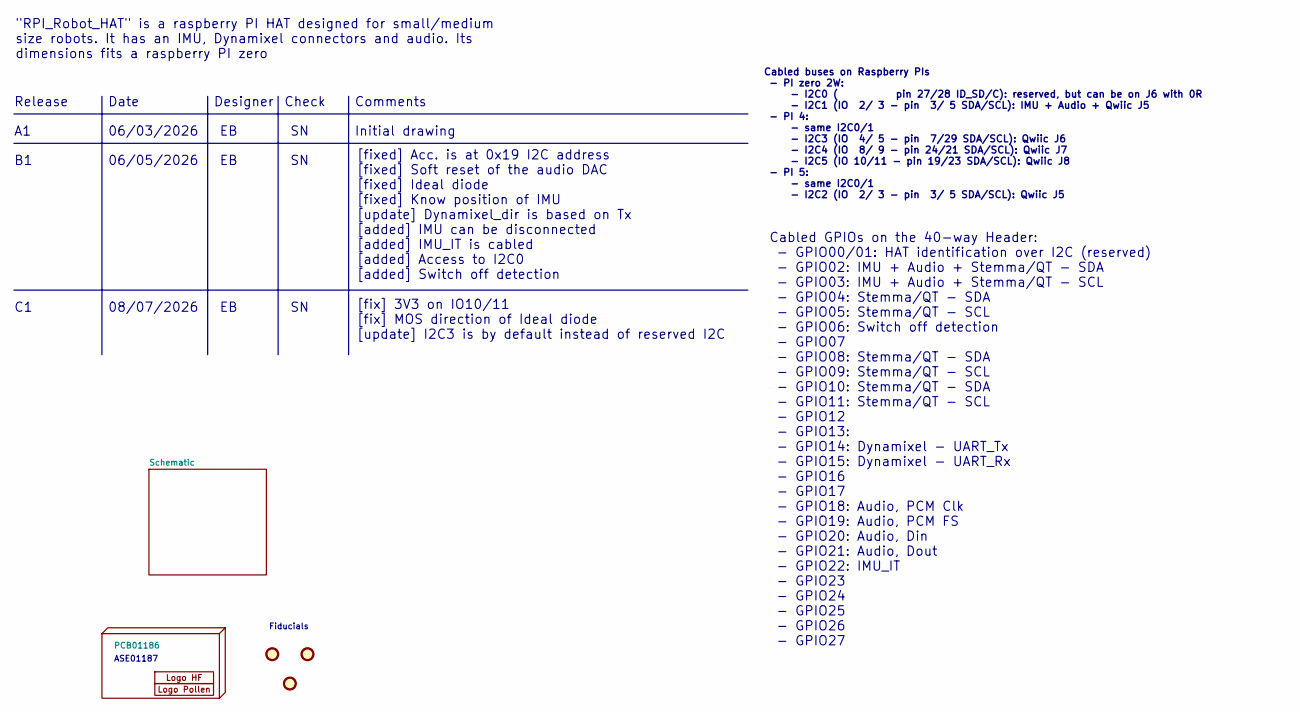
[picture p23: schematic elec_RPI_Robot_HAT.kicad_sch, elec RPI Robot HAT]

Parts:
FID1, FID2, FID3: DNP Fiducial; Fiducial_1mm_Mask2mm
H1: PCB01186
H2: Logo HF 2025; Logo_HF_2025
H3: DNP Logo Pollen 2021; Logo_Pollen_2021_sq

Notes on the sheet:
[fixed] Acc. is at 0x19 I2C address [fixed] Soft reset of the audio DAC [fixed] Ideal diode [fixed] Know position of IMU [update] Dynamixel_dir is based on Tx [added] IMU can be disconnected [added] IMU_IT is cabled [added] Access to I2C0 [added] Switch off detection
Date
[fix] 3V3 on IO10/11 [fix] MOS direction of Ideal diode [update] I2C3 is by default instead of reserved I2C
Check
Release
Fiducials
Cabled buses on Raspberry PIs - PI zero 2W: - I2C0 ( pin 27/28 ID_SD/C): reserved, but can be on J6 with 0R - I2C1 (IO 2/ 3 - pin 3/ 5 SDA/SCL): IMU + Audio + Qwiic J5 - PI 4: - same I2C0/1 - I2C3 (IO 4/ 5 - pin 7/29 SDA/SCL): Qwiic J6 - I2C4 (IO 8/ 9 - pin 24/21 SDA/SCL): Qwiic J7 - I2C5 (IO 10/11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
08/07/2026
ASE01187
06/05/2026
Initial drawing
"RPI_Robot_HAT" is a raspberry PI HAT designed for small/medium size robots. It has an IMU, Dynamixel connectors and audio. Its dimensions fits a raspberry PI zero
Designer
Cabled GPIOs on the 40-way Header: - GPIO00/01: HAT identification over I2C (reserved) - GPIO02: IMU + Audio + Stemma/QT - SDA - GPIO03: IMU + Audio + Stemma/QT - SCL - GPIO04: Stemma/QT - SDA - GPIO05: Stemma/QT - SCL - GPIO06: Switch off detection - GPIO07 - GPIO08: Stemma/QT - SDA - GPIO09: Stem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
Comments
06/03/2026

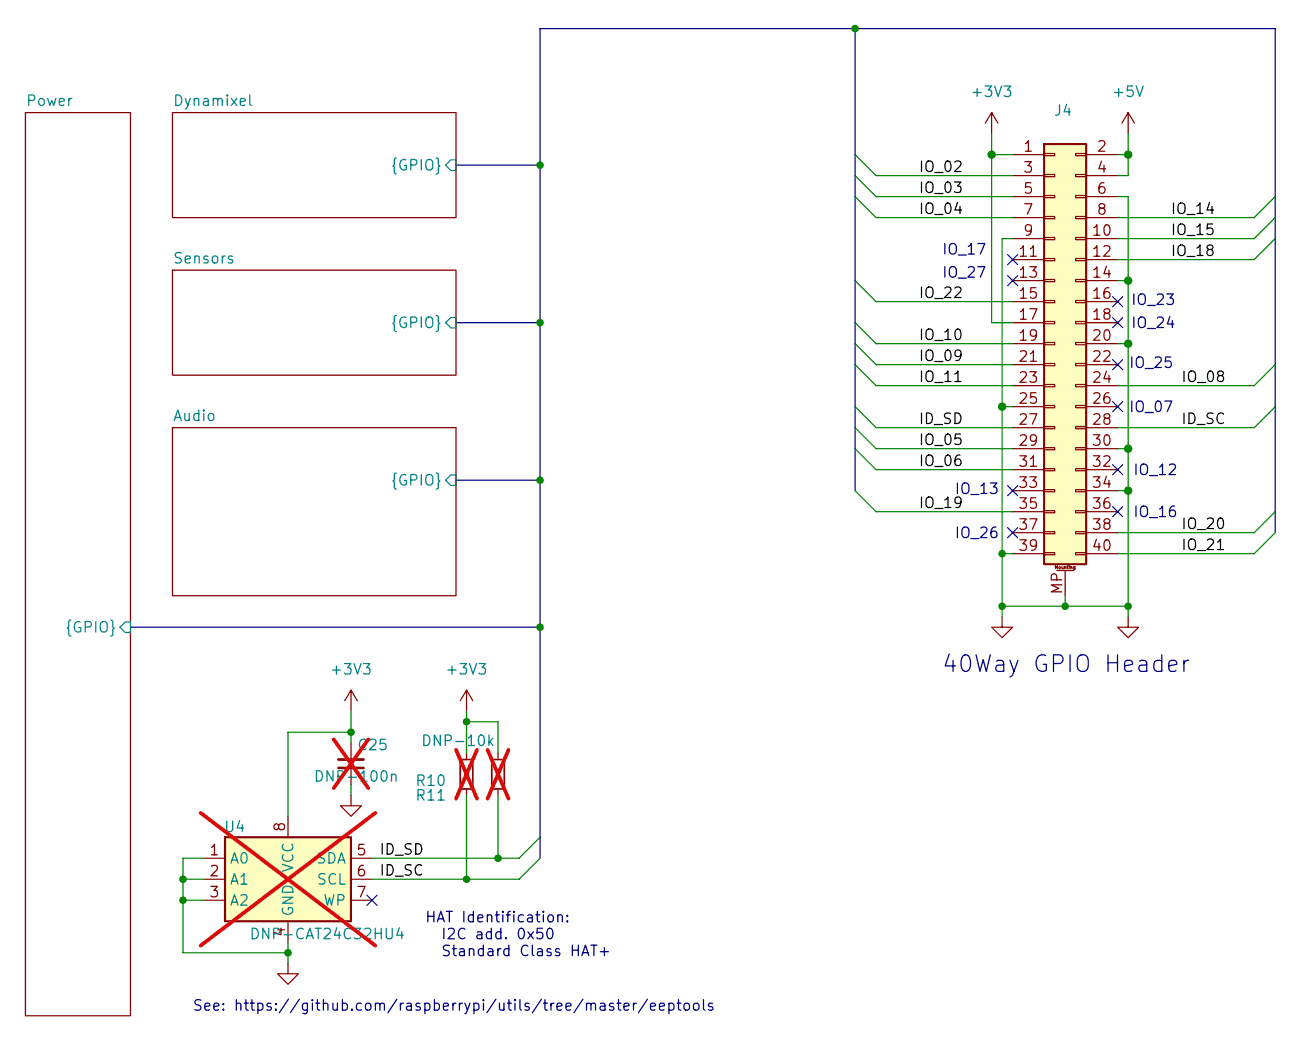
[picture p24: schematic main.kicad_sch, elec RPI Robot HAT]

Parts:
C25: DNP-100n; C_0402_1005Metric; not fitted
J4: Female Header 2x20 SMD; PinHeader_2x20_P2.54mm_Vertical_with_rasp_HAT_zero_SMD_conn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; Part Description PinHeader_2x20_P2.54mm_Vertical; LCSC Part C2685112
R10, R11: DNP-10k; R_0402_1005Metric; not fitted
U4: DNP-CAT24C32HU4; TDFN-8_L3.0-W2.0-P0.50-BL-EP; not fitted

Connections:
+3V3: C25.2, J4.1, J4.17, R10.1, R11.1, U4.8 (VCC); also elsewhere on the board
+5V: J4.2, J4.4; also elsewhere on the board
/Schematic/Audio/ID_SC: J4.28, R10.2, U4.6 (SCL); also elsewhere on the board
/Schematic/Audio/ID_SD: J4.27, R11.2, U4.5 (SDA); also elsewhere on the board
/Schematic/Audio/IO_02: J4.3; also elsewhere on the board
/Schematic/Audio/IO_03: J4.5; also elsewhere on the board
/Schematic/Audio/IO_04: J4.7; also elsewhere on the board
/Schematic/Audio/IO_05: J4.29; also elsewhere on the board
/Schematic/Audio/IO_06: J4.31; also elsewhere on the board
/Schematic/Audio/IO_08: J4.24; also elsewhere on the board
/Schematic/Audio/IO_09: J4.21; also elsewhere on the board
/Schematic/Audio/IO_10: J4.19; also elsewhere on the board
/Schematic/Audio/IO_11: J4.23; also elsewhere on the board
/Schematic/Audio/IO_14: J4.8; also elsewhere on the board
/Schematic/Audio/IO_15: J4.10; also elsewhere on the board
/Schematic/Audio/IO_18: J4.12; also elsewhere on the board
/Schematic/Audio/IO_19: J4.35; also elsewhere on the board
/Schematic/Audio/IO_20: J4.38; also elsewhere on the board
/Schematic/Audio/IO_21: J4.40; also elsewhere on the board
/Schematic/Audio/IO_22: J4.15; also elsewhere on the board
GND: C25.1, J4.6, J4.9, J4.14, J4.20, J4.25, J4.30, J4.34, J4.39, J4.MP (MountPin), U4.1 (A0), U4.2 (A1), U4.3 (A2), U4.4 (GND); also elsewhere on the board

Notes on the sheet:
IO_07
IO_23
40Way GPIO Header
IO_13
IO_24
HAT Identification: I2C add. 0x50 Standard Class HAT+
IO_25
IO_17
IO_12
See: https://github.com/raspberrypi/utils/tree/master/eeptools
IO_16
IO_26
IO_27

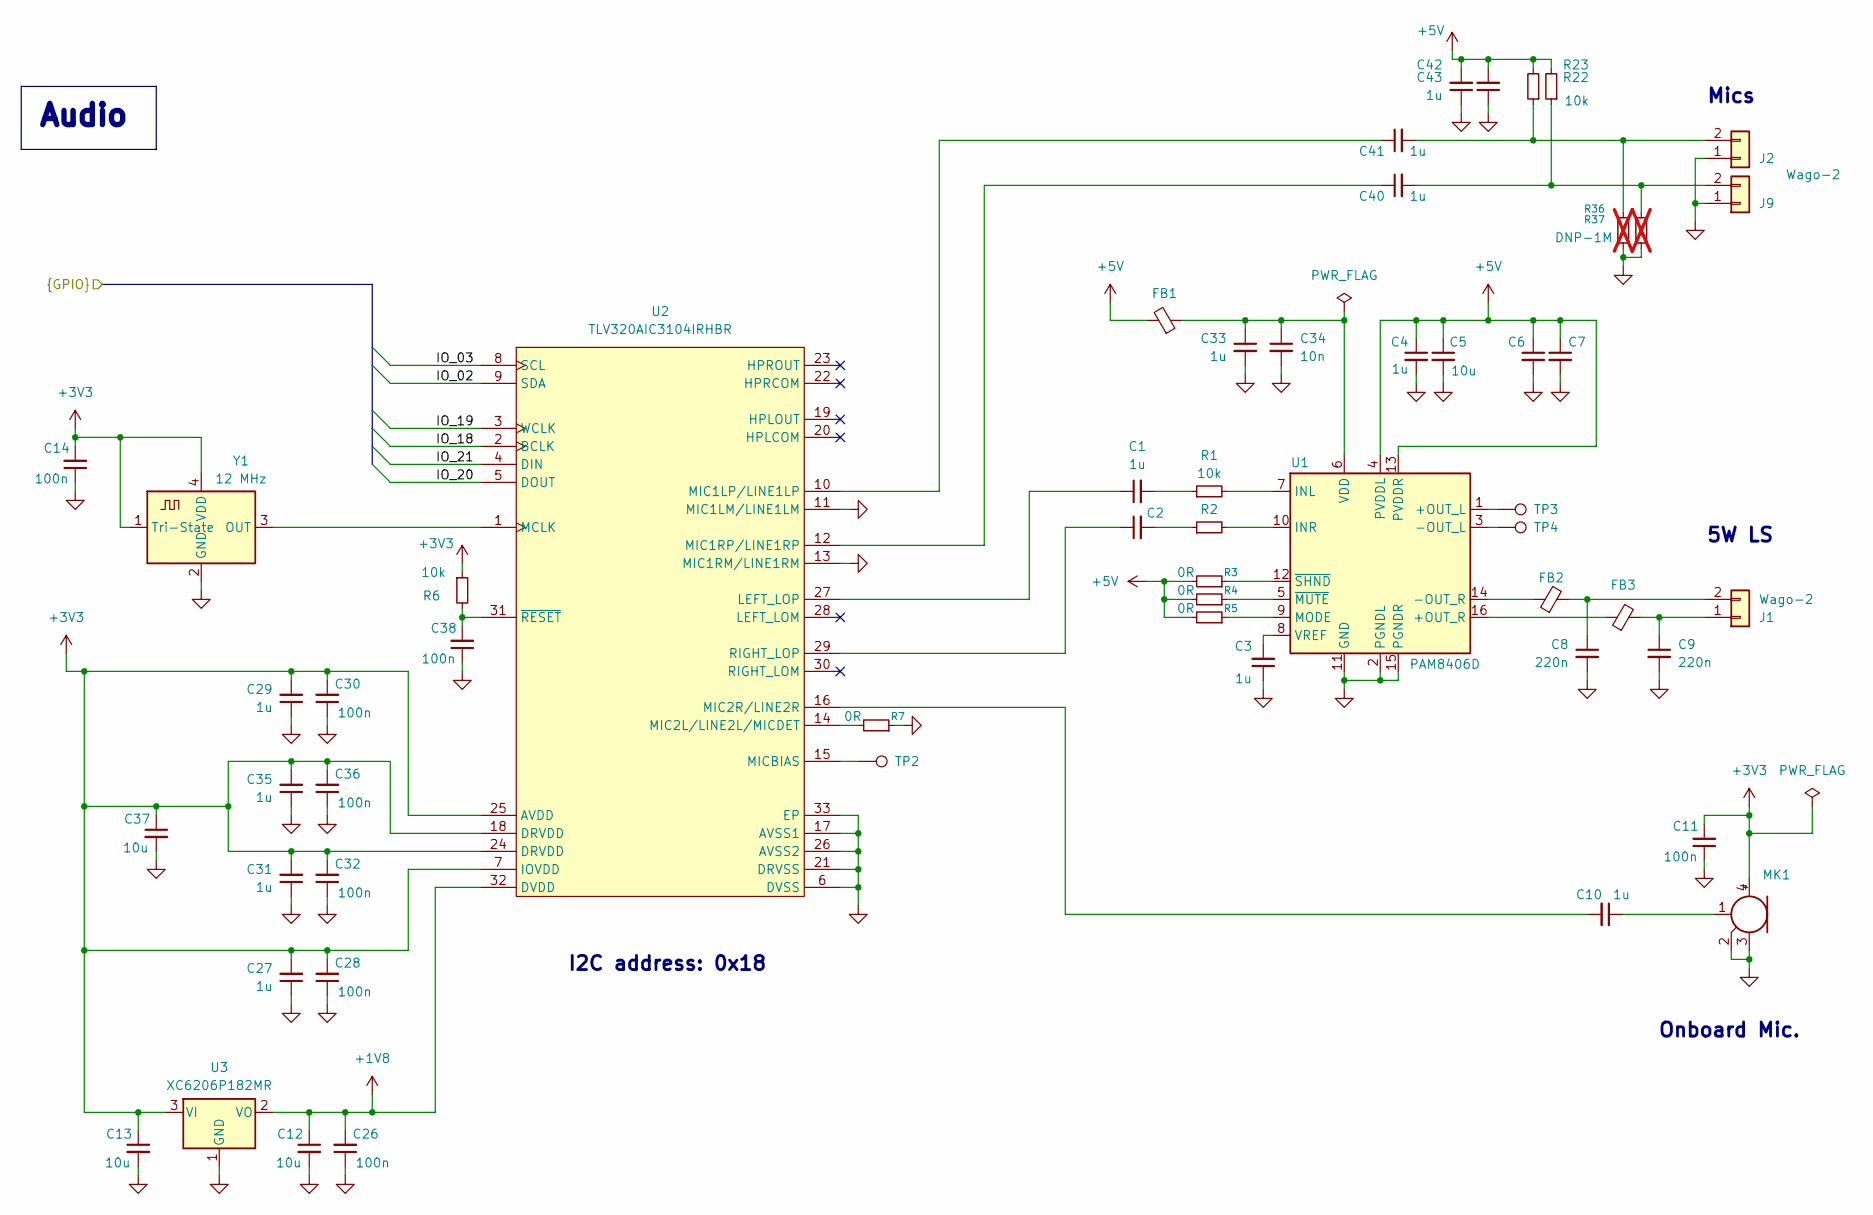
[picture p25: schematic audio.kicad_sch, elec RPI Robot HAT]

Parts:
C1, C2, C3, C4, C6, C10, C27, C29, C31, C33, C35, C40, C41, C42, C43: 1u; C_0402_1005Metric; LCSC Part C52923
C5, C7, C12, C13, C37: 10u; C_0603_1608Metric; LCSC Part C1691
C8, C9: 220n; C_0402_1005Metric; LCSC Part C71693
C11, C14, C26, C28, C30, C32, C36, C38: 100n; C_0402_1005Metric; LCSC Part C307331
C34: 10n; C_0402_1005Metric; LCSC Part C15195
FB1: 1.3A 600R@100MHz; L_0402_1005Metric; LCSC Part C76884
FB2, FB3: 2A - 120R@100MHz; L_0402_1005Metric; LCSC Part C88970
J1, J2, J9: Wago-2; Wago_2059-302_998-403; LCSC Part C2765060
MK1: Microphone_MEMS; MIC-SMD_4P-L2.8-W1.9-P1.84-TL; LCSC Part C7587901
R1, R2, R6, R22, R23: 10k; R_0402_1005Metric; LCSC Part C25744
R3, R4, R5, R7: 0R; R_0402_1005Metric; LCSC Part C17168
R36, R37: DNP-1M; R_0402_1005Metric; LCSC Part C17168; not fitted
TP2, TP3, TP4: TestPoint; TestPoint_Loop_D2.50mm_Drill1.0mm_LowProfile
U1: PAM8406D; SOIC-16_3.9x9.9mm_P1.27mm; LCSC Part C86270
U2: TLV320AIC3104IRHBR; VQFN-32-1EP_5x5mm_P0.5mm_EP3.5x3.5mm; LCSC Part C181753
U3: XC6206P182MR; SOT-23-3; LCSC Part C347373
Y1: 12 MHz; Oscillator_SMD_Abracon_ASDMB-4Pin_2.5x2.0mm; LCSC Part C7425459

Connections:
+1V8: C12.1, C26.2, U2.32 (DVDD), U3.2 (VO)
+3V3: C11.2, C13.1, C14.2, C27.2, C28.2, C29.2, C30.2, C31.2, C32.2, C35.2, C36.2, C37.1, MK1.4 (+), R6.1, U2.7 (IOVDD), U2.18 (DRVDD), U2.24 (DRVDD), U2.25 (AVDD), U3.3 (VI), Y1.1 (Tri-State), Y1.4 (VDD); also elsewhere on the board
+5V: C4.1, C5.1, C6.1, C7.1, C42.2, C43.2, FB1.2, R3.2, R4.2, R5.2, R22.2, R23.2, U1.4 (PVDDL), U1.13 (PVDDR); also elsewhere on the board
/Schematic/Audio/IO_02: U2.9 (SDA); also elsewhere on the board
/Schematic/Audio/IO_03: U2.8 (SCL); also elsewhere on the board
/Schematic/Audio/IO_18: U2.2 (BCLK); also elsewhere on the board
/Schematic/Audio/IO_19: U2.3 (WCLK); also elsewhere on the board
/Schematic/Audio/IO_20: U2.5 (DOUT); also elsewhere on the board
/Schematic/Audio/IO_21: U2.4 (DIN); also elsewhere on the board
GND: C3.1, C4.2, C5.2, C6.2, C7.2, C8.2, C9.2, C11.1, C12.2, C13.2, C14.1, C26.1, C27.1, C28.1, C29.1, C30.1, C31.1, C32.1, C33.2, C34.2, C35.1, C36.1, C37.2, C38.1, C42.1, C43.1, J2.1, J9.1, MK1.2 (-), MK1.3 (-), R7.1, R36.1, R37.1, U1.2 (PGNDL), U1.11 (GND), U1.15 (PGNDR), U2.6 (DVSS), U2.11 (MIC1LM/LINE1LM), U2.13 (MIC1RM/LINE1RM), U2.17 (AVSS1), U2.21 (DRVSS), U2.26 (AVSS2), U2.33 (EP), U3.1 (GND), Y1.2 (GND); also elsewhere on the board
unnamed: C1.2, R1.1
unnamed: C2.2, R2.1
unnamed: C10.1, MK1.1 (-)
unnamed: C9.1, FB3.2, J1.1
unnamed: C8.1, FB2.2, J1.2
unnamed: C41.2, J2.2, R22.1, R36.2
unnamed: C40.2, J9.2, R23.1, R37.2
unnamed: TP3.1, U1.1 (+OUT_L)
unnamed: FB3.1, U1.16 (+OUT_R)
unnamed: TP4.1, U1.3 (-OUT_L)
unnamed: FB2.1, U1.14 (-OUT_R)
unnamed: R1.2, U1.7 (INL)
unnamed: R2.2, U1.10 (INR)
unnamed: R5.1, U1.9 (MODE)
unnamed: C33.1, C34.1, FB1.1, U1.6 (VDD)
unnamed: C3.2, U1.8 (VREF)
unnamed: R4.1, U1.5 (~MUTE)
unnamed: R3.1, U1.12 (~SHND)
unnamed: C1.1, U2.27 (LEFT_LOP)
unnamed: U2.1 (MCLK), Y1.3 (OUT)
unnamed: C41.1, U2.10 (MIC1LP/LINE1LP)
unnamed: C40.1, U2.12 (MIC1RP/LINE1RP)
unnamed: R7.2, U2.14 (MIC2L/LINE2L/MICDET)
unnamed: C10.2, U2.16 (MIC2R/LINE2R)
unnamed: TP2.1, U2.15 (MICBIAS)
unnamed: C2.1, U2.29 (RIGHT_LOP)
unnamed: C38.2, R6.2, U2.31 (~RESET)

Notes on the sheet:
Onboard Mic.
5W LS
Mics
I2C address: 0x18
Audio

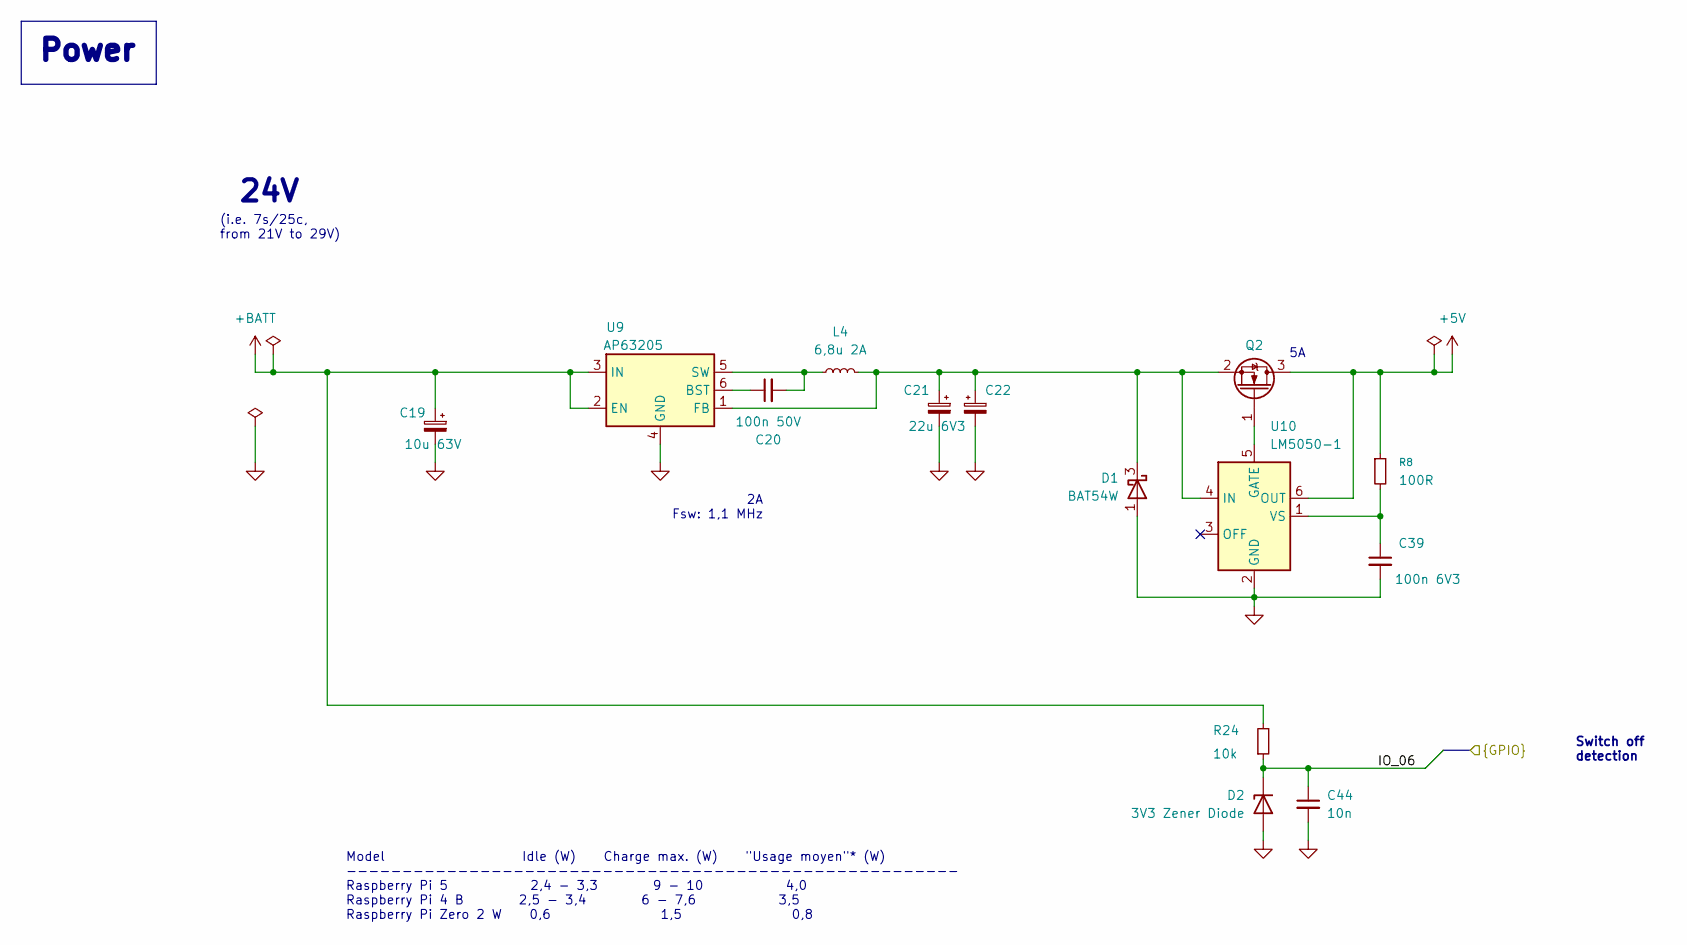
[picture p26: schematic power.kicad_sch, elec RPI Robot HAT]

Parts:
C19: 10u 63V; CP_Elec_6.3x7.7; LCSC Part C72488
C20: 100n 50V; C_0402_1005Metric; LCSC Part C307331
C21, C22: 22u 6V3; C_0603_1608Metric; LCSC Part C84419
C39: 100n 6V3; C_0402_1005Metric; LCSC Part C1525
C44: 10n; C_0402_1005Metric; LCSC Part C15195
D1: BAT54W; SOT-323_SC-70; LCSC Part C78606
D2: 3V3 Zener Diode; D_SOD-123; LCSC Part C19077392
L4: 6,8u 2A; L_Bourns_SRN6045TA; LCSC Part C57254
Q2: SI2312CDS-T1-GE3; TSOT-23; LCSC Part C142518
R8: 100R; R_0402_1005Metric; LCSC Part C2906860
R24: 10k; R_0402_1005Metric; LCSC Part C25744
U9: AP63205; TSOT-23-6; LCSC Part C2071056
U10: LM5050-1; TSOT-23-6; LCSC Part C473393

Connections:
+5V: Q2.3 (D), R8.1, U10.6 (OUT); also elsewhere on the board
+BATT: C19.1, R24.2, U9.2 (EN), U9.3 (IN); also elsewhere on the board
/Schematic/Audio/IO_06: C44.1, D2.1 (K), R24.1; also elsewhere on the board
GND: C19.2, C21.2, C22.2, C39.2, C44.2, D1.1 (A), D2.2 (A), U9.4 (GND), U10.2 (GND); also elsewhere on the board
unnamed: C21.1, C22.1, D1.3 (K), L4.1, Q2.2 (S), U9.1 (FB), U10.4 (IN)
unnamed: Q2.1 (G), U10.5 (GATE)
unnamed: C20.1, U9.6 (BST)
unnamed: C20.2, L4.2, U9.5 (SW)
unnamed: C39.1, R8.2, U10.1 (VS)

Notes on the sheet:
Switch off detection
24V
Model Idle (W) Charge max. (W) "Usage moyen"* (W) ------------------------------------------------------- Raspberry Pi 5 2,4 - 3,3 9 - 10 4,0 Raspberry Pi 4 B 2,5 - 3,4 6 - 7,6 3,5 Raspberry Pi Zero 2 W 0,6 1,5 0,8
(i.e. 7s/25c, from 21V to 29V)
2A Fsw: 1,1 MHz
Power

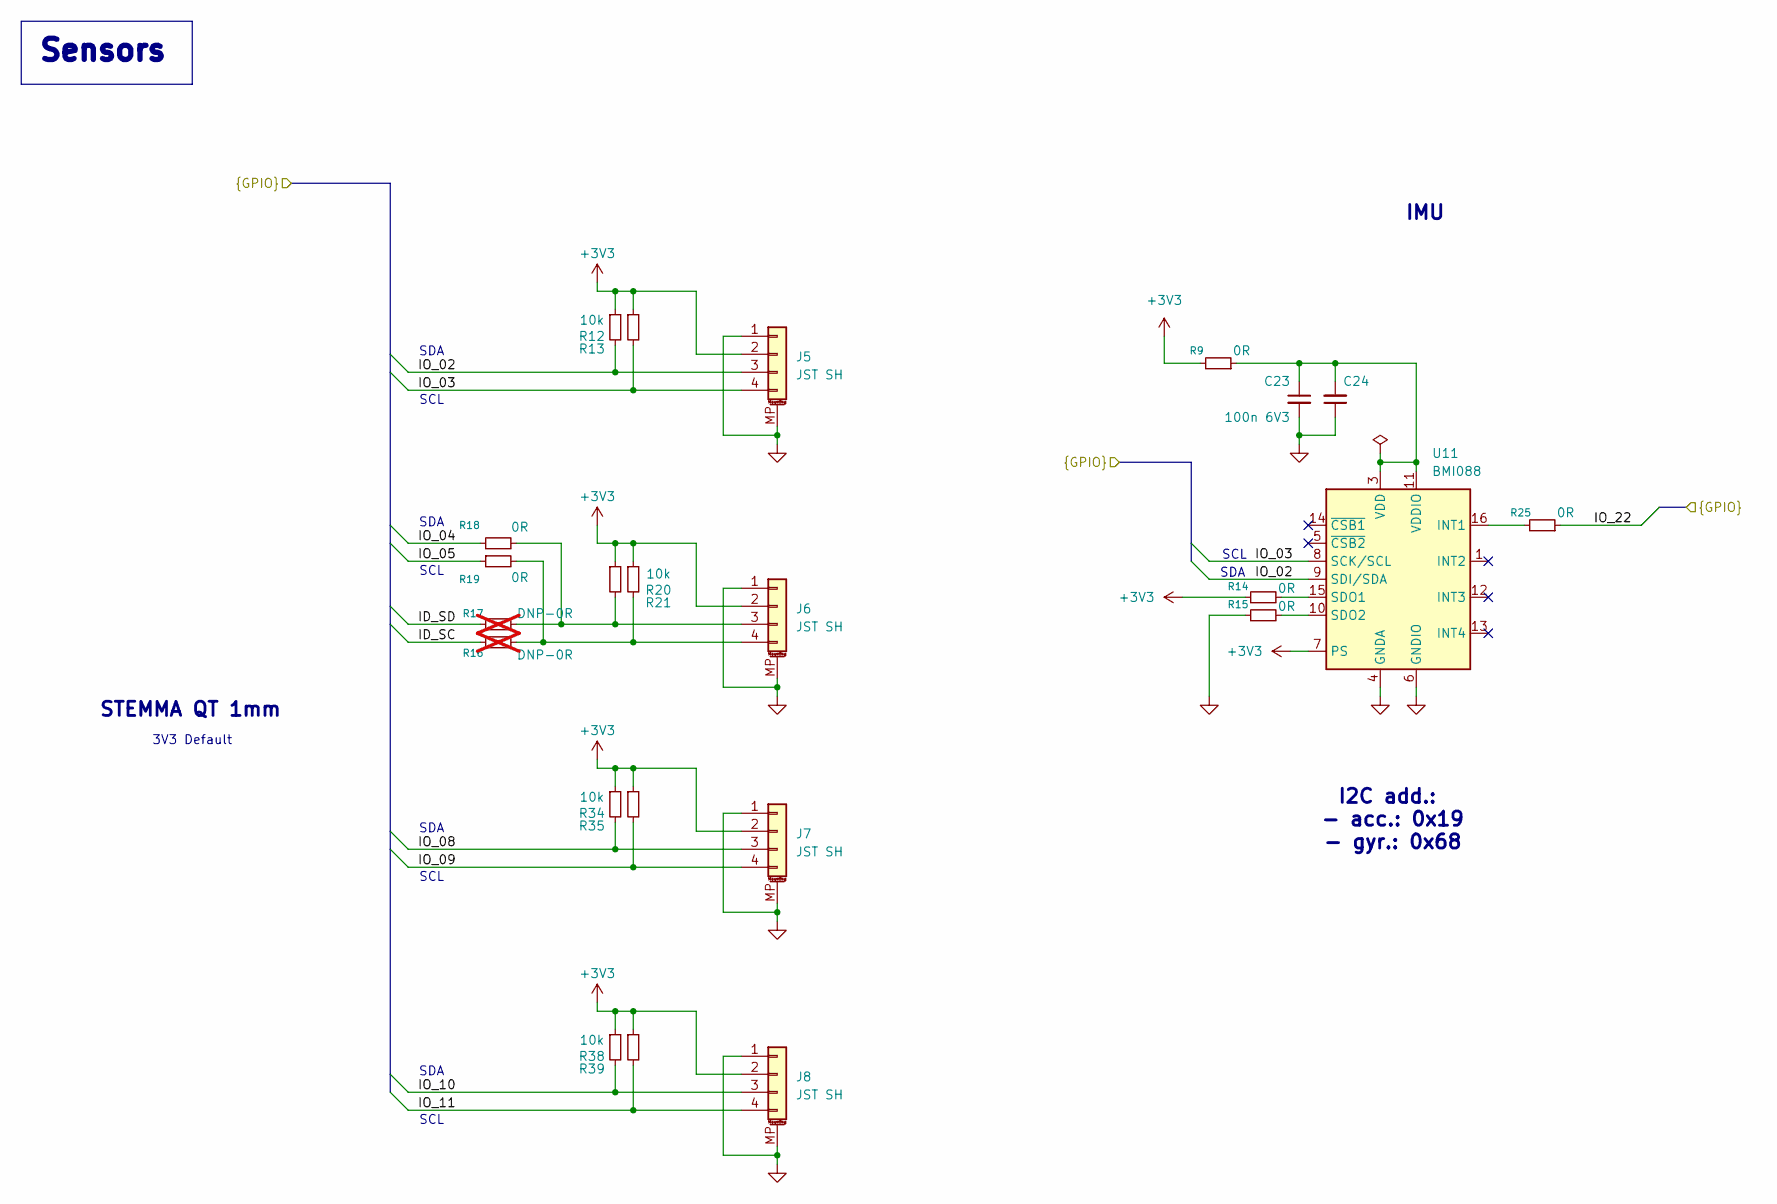
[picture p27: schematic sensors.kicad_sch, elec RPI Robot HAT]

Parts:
C23, C24: 100n 6V3; C_0402_1005Metric; LCSC Part C1525
J5, J6, J7, J8: JST SH; JST_SH_BM04B-SRSS-TB_1x04-1MP_P1.00mm_Vertical; LCSC Part C160390
R9, R14, R15, R18, R19, R25: 0R; R_0402_1005Metric; LCSC Part C17168
R12, R13, R20, R21, R34, R35, R38, R39: 10k; R_0402_1005Metric; LCSC Part C25744
R16, R17: DNP-0R; R_0402_1005Metric; not fitted
U11: BMI088; Bosch_LGA-16_4.5x3mm_P0.5mm_LayoutBorder7x1y_ClockwisePinNu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; LCSC Part C194919

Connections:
+3V3: J5.2, J6.2, J7.2, J8.2, R9.2, R12.1, R13.1, R14.1, R20.1, R21.1, R34.1, R35.1, R38.1, R39.1, U11.7 (PS); also elsewhere on the board
/Schematic/Audio/ID_SC: R16.1; also elsewhere on the board
/Schematic/Audio/ID_SD: R17.1; also elsewhere on the board
/Schematic/Audio/IO_02: J5.3, R12.2, U11.9 (SDI/SDA); also elsewhere on the board
/Schematic/Audio/IO_03: J5.4, R13.2, U11.8 (SCK/SCL); also elsewhere on the board
/Schematic/Audio/IO_04: R18.1; also elsewhere on the board
/Schematic/Audio/IO_05: R19.1; also elsewhere on the board
/Schematic/Audio/IO_08: J7.3, R34.2; also elsewhere on the board
/Schematic/Audio/IO_09: J7.4, R35.2; also elsewhere on the board
/Schematic/Audio/IO_10: J8.3, R38.2; also elsewhere on the board
/Schematic/Audio/IO_11: J8.4, R39.2; also elsewhere on the board
/Schematic/Audio/IO_22: R25.1; also elsewhere on the board
GND: C23.2, C24.1, J5.1, J5.MP (MountPin), J6.1, J6.MP (MountPin), J7.1, J7.MP (MountPin), J8.1, J8.MP (MountPin), R15.1, U11.2 (GNDA), U11.4 (GNDA), U11.6 (GNDIO); also elsewhere on the board
unnamed: J6.3, R17.2, R18.2, R20.2
unnamed: J6.4, R16.2, R19.2, R21.2
unnamed: R25.2, U11.16 (INT1)
unnamed: R14.2, U11.15 (SDO1)
unnamed: R15.2, U11.10 (SDO2)
unnamed: C23.1, C24.2, R9.1, U11.3 (VDD), U11.11 (VDDIO)

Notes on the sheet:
SCL
SDA
I2C add.: - acc.: 0x19 - gyr.: 0x68
IMU
STEMMA QT 1mm
3V3 Default
Sensors

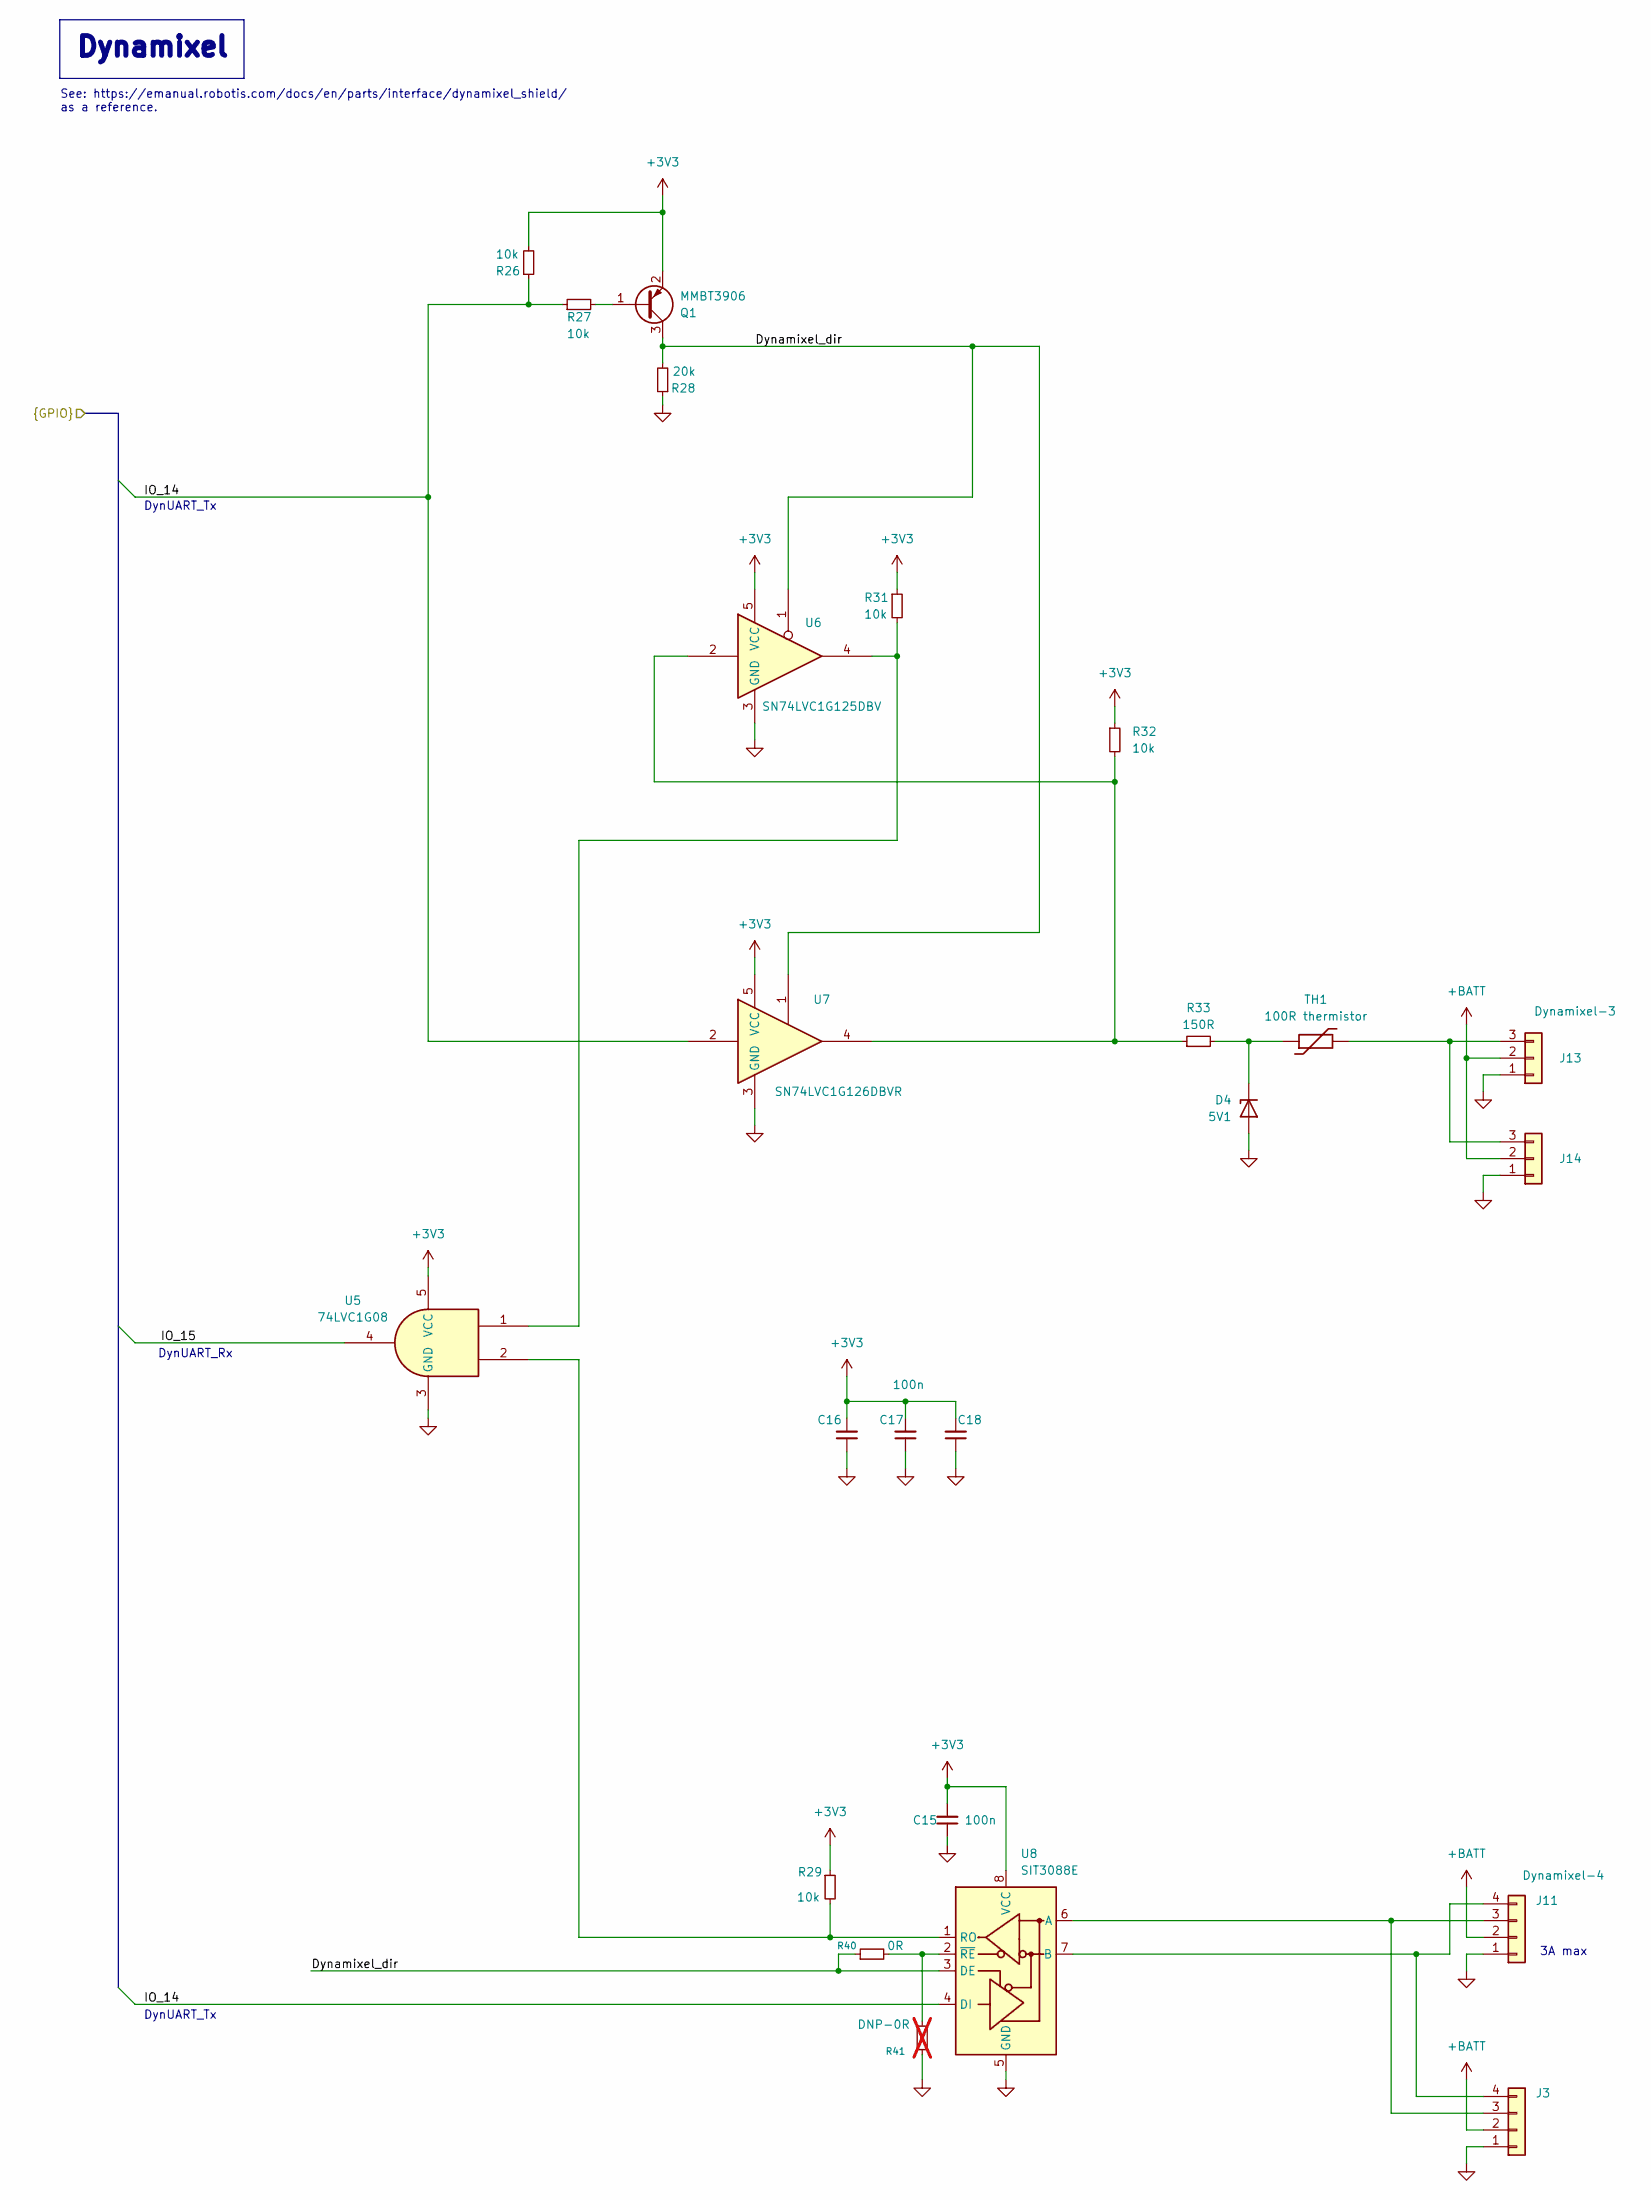
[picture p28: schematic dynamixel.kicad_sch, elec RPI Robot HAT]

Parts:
C15, C16, C17, C18: 100n; C_0402_1005Metric; LCSC Part C307331
D4: 5V1; D_SOD-323; LCSC Part C151348
J3, J11: Dynamixel-4; JST_EH_B4B-EH-A_1x04_P2.50mm_Vertical; LCSC Part C160258
J13, J14: Dynamixel-3; JST_EH_B3B-EH-A_1x03_P2.50mm_Vertical; LCSC Part C160259
Q1: MMBT3906; SOT-23; LCSC Part C727128
R26, R27, R29, R31, R32: 10k; R_0402_1005Metric; LCSC Part C25744
R28: 20k; R_0402_1005Metric; LCSC Part C25765
R33: 150R; R_0402_1005Metric; LCSC Part C138054
R40: 0R; R_0402_1005Metric; LCSC Part C17168
R41: DNP-0R; R_0402_1005Metric; not fitted
TH1: 100R thermistor; R_0603_1608Metric; LCSC Part C913703
U5: 74LVC1G08; SOT-23-5; LCSC Part C7666
U6: SN74LVC1G125DBV; SOT-23-5; LCSC Part C3040625
U7: SN74LVC1G126DBVR; SOT-23-5; LCSC Part C7834
U8: SIT3088E; MSOP-8-1EP_3x3mm_P0.65mm_EP1.5x1.8mm; LCSC Part C2922535

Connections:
+3V3: C15.2, C16.2, C17.2, C18.2, Q1.2 (E), R26.2, R29.1, R31.1, R32.1, U5.5 (VCC), U6.5 (VCC), U7.5 (VCC), U8.8 (VCC); also elsewhere on the board
+BATT: J3.2, J11.2, J13.2, J14.2; also elsewhere on the board
/Schematic/Audio/IO_14: R26.1, R27.1, U7.2, U8.4 (DI); also elsewhere on the board
/Schematic/Audio/IO_15: U5.4; also elsewhere on the board
/Schematic/Dynamixel/Dynamixel_dir: Q1.3 (C), R28.2, R40.1, U6.1, U7.1, U8.3 (DE)
GND: C15.1, C16.1, C17.1, C18.1, D4.2 (A), J3.1, J11.1, J13.1, J14.1, R28.1, R41.1, U5.3 (GND), U6.3 (GND), U7.3 (GND), U8.5 (GND); also elsewhere on the board
unnamed: D4.1 (K), R33.2, TH1.1
unnamed: J3.3, J11.3, U8.6 (A)
unnamed: J3.4, J11.4, U8.7 (B)
unnamed: J13.3, J14.3, TH1.2
unnamed: Q1.1 (B), R27.2
unnamed: R31.2, U5.1, U6.4
unnamed: R32.2, R33.1, U6.2, U7.4
unnamed: R29.2, U5.2, U8.1 (RO)
unnamed: R40.2, R41.2, U8.2 (~RE)

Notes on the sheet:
DynUART_Tx
DynUART_Rx
See: https://emanual.robotis.com/docs/en/parts/interface/dynamixel_shield/ as a reference.
3A max
Dynamixel

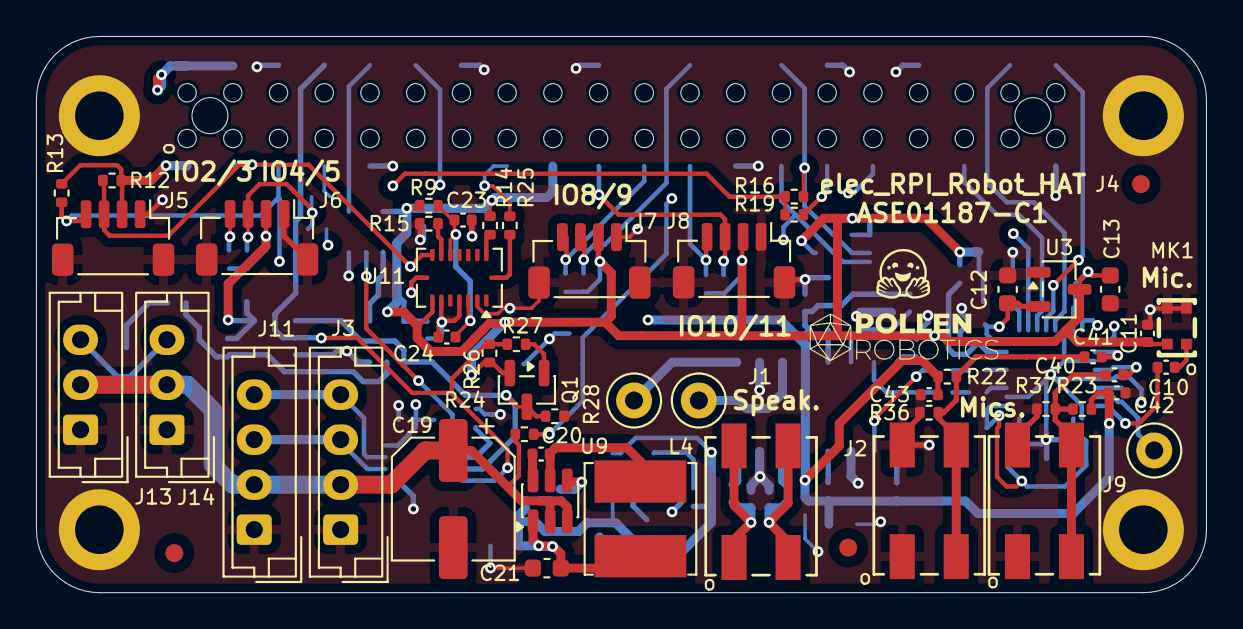
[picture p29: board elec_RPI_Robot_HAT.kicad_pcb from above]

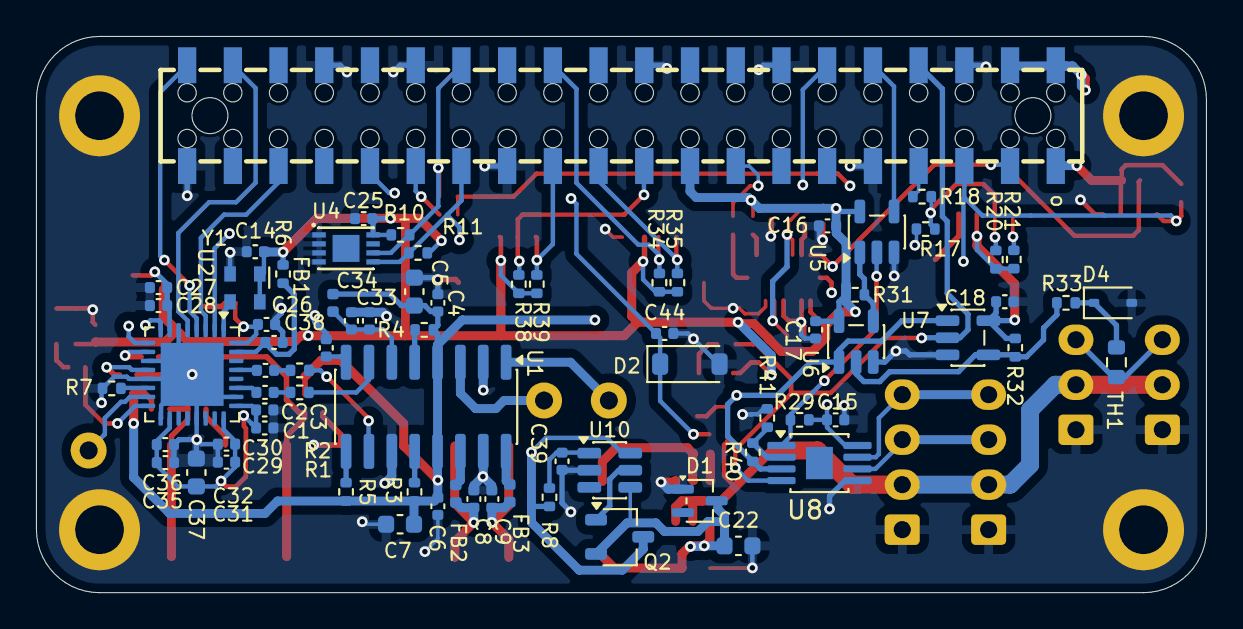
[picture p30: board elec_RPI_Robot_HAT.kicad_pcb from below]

Board: 4 copper layers, 65.0 x 30.9 mm, 127 parts (73 on the bottom side), 71 nets.

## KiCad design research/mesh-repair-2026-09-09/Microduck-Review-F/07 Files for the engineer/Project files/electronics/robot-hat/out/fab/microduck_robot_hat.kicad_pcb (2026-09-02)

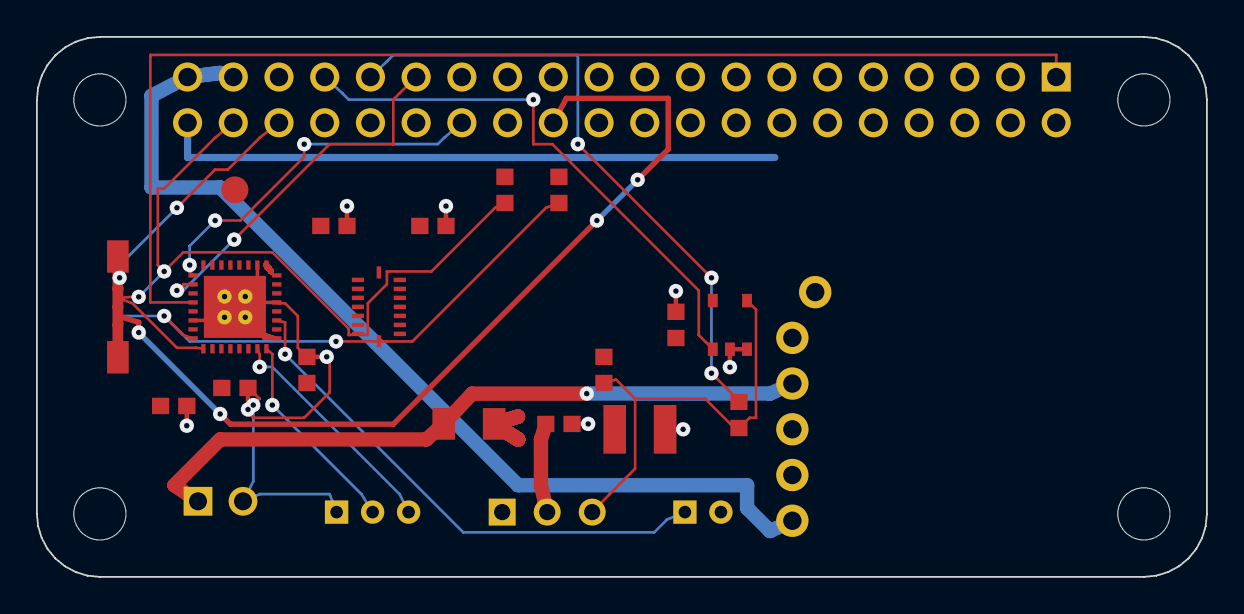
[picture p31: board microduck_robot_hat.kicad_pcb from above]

Board: 2 copper layers, 65.0 x 30.0 mm, 28 parts (0 on the bottom side), 21 nets.

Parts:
C1: 100n SERVO_V; 0603
C2: bulk (value CANNOT DETERMINE); 1210
C3: 100n U4 VCC; 0603
C4, C5, C6, C7, C8: 100n; 0603
H1, H2, H3, H4: M2.5; mount-M2.5
J1: 40-pin GPIO; header-2x20
J2: VBAT in (B2B-XH-A); jst-b2b-xh-a
J3: DXL bus (B3B-EH-A); jst-b3b-eh-a
J5: Stemma J5 (SM04B-SRSS-TB); jst-sh4-smt-side
J6: speaker (B2B-PH-K-S); jst-b2b-ph-k-s
J7: mic (B3B-PH-K-S); jst-b3b-ph-k-s
R1: 0R link VBAT->SERVO_V; 1206
R2, R12, R13: 10k; 0603
R4: 0R DATA->RX; 0603
TP1: HAT_1V8 (unsourced); test-point
U1: TLV320AIC3104; qfn-32
U2: Pololu D30V30F5; pololu-d30v30f5
U3: BMI088 (dormant); bmi088-lga16
U4: 74LVC1G125; sot753

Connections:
GND: C1.2, C2.2, C3.2, C4.2, C5.2, C6.2, C7.2, C8.2, J1.6, J1.9, J1.14, J1.20, J1.25, J1.30, J1.34, J1.39, J2.2, J3.1, J5.1, J7.1, U1.6, U1.17, U1.21, U1.26, U1.EP, U2.GND1, U2.GND2, U3.2, U3.4, U3.6, U3.10, U3.15, U4.2, U4.3
HAT_1V8: C5.1, TP1.1, U1.32
HAT_3V3: C3.1, C4.1, C6.1, C7.1, C8.1, J1.1, R2.2, R12.2, R13.2, U1.7, U1.18, U1.24, U1.25, U1.31, U3.3, U3.7, U3.11, U3.14, U4.5
J5_3V3: J1.17, J5.2
MICBIAS: J7.3, U1.15
MIC_IN: J7.2, U1.16
SERVO_V: C1.1, C2.1, J3.2, R1.2
SPK_N: J6.2, U1.20
SPK_P: J6.1, U1.19
V5_HAT: J1.2, J1.4, U2.VOUT
VBAT: J2.1, R1.1, U2.VIN
dxl/DATA: J3.3, R2.1, R4.1, U4.4
i2c3/SCL: J1.5, J5.4, R13.1, U1.8, U3.8
i2c3/SDA: J1.3, J5.3, R12.1, U1.9, U3.9
i2s3/BCLK: J1.12, U1.2
i2s3/DIN: J1.40, U1.4
i2s3/DOUT: J1.38, U1.5
i2s3/MCLK: J1.13, U1.1
i2s3/WCLK: J1.35, U1.3
uart2/RX: J1.10, R4.2
uart2/TX: J1.8, U4.1

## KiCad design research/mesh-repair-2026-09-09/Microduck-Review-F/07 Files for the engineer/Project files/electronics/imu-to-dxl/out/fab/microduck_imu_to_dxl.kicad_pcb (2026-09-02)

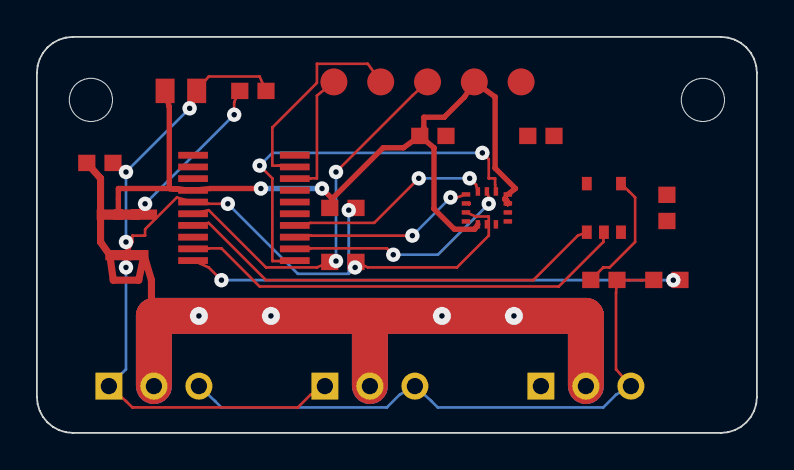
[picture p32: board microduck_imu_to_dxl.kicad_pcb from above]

Board: 2 copper layers, 40.0 x 22.0 mm, 24 parts (0 on the bottom side), 17 nets.

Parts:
C1: 1u CIN; 0603
C2: 4u7 COUT; 0805
C3: 10n BYPASS; 0603
C4, C5, C6, C7: 100n; 0603
C8: 100n NRST; 0603
H1, H2: M2; mount-M2
J1, J2, J3: DXL bus (B3B-EH-A); jst-b3b-eh-a
R1: 0R DXL_DATA->U3.Y; 0603
R2: 0R DXL_DATA->RX; 0603
TP1: SWDIO; test-point
TP2: SWCLK; test-point
TP3: NRST; test-point
TP4: 3V3; test-point
TP5: GND; test-point
U1: LSM6DSV16X; lga-14l-2p5x3
U2: STM32G031F6P6; tssop-20
U3: 74LVC1G125; sot753
U4: LP2985A-33DBVR; sot-23-5

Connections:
BYPASS: C3.1, U4.4
DIR: U2.7, U3.1
DXL_DRV: R1.1, U3.4
GND: C1.2, C2.2, C3.2, C4.2, C5.2, C6.2, C7.2, C8.2, J1.1, J2.1, J3.1, TP5.1, U1.2, U1.3, U1.6, U1.7, U2.5, U3.3, U4.2
IMU_INT1: U1.4, U2.8
MCU_RX: R2.2, U2.10
MCU_TX: U2.9, U3.2
NRST: C8.1, TP3.1, U2.6
SERVO_V: C1.1, J1.2, J2.2, J3.2, U4.1, U4.3
SPI_MISO: U1.1, U2.13
SPI_MOSI: U1.14, U2.14
SPI_NSS: U1.12, U2.11
SPI_SCK: U1.13, U2.12
SWCLK: TP2.1, U2.19
SWDIO: TP1.1, U2.18
V3V3: C2.1, C4.1, C5.1, C6.1, C7.1, TP4.1, U1.5, U1.8, U1.10, U1.11, U2.4, U3.5, U4.5
dxl/DATA: J1.3, J2.3, J3.3, R1.2, R2.1

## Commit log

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2026-09-01 assembly:microduck seeded from the MJCF: 38 bom rows, 70 placements with provenance, 14 hinges (2 resolved by measurement onto the shin)
    [ankle_r_v1_mirrored_x.stl, ankle_right_mirrored_x.stl]
2026-09-01 rebuild pass 1 + docs: 9 parts PASS, PARTS/ELECTRONICS-AND-SOFTWARE/BOM docs, TOOLCHAIN pin, qty fix; a 161 MB ASCII STL dropped (GitHub 100 MB cap) and a pre-commit guard added
    [ours.stl, roll_servo_in_y2r.stl, y2r_context.stl]
2026-09-01 quick path: 14 mesh-backed parts shelved from Pollen's meshes (origin vendor, CC BY-SA-NC noted), joint interfaces derived from the MJCF; assembly re-seeded 5/14 joints resolved
    Leif, 2026-09-01: 'why not use the reference mesh directly?' — cecad.meshshelve
    + cad-mjcf shelve. A parametric rebuild replaces a slug's contents later.
    [foot_left.stl, foot_right.stl, jaw.stl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]
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2026-09-01 overnight snapshot 01:52: electronics datasheets on the shelf (xl330-m288-t, lsm6dsv16x, +), production research docs (components, process, compliance), sim lane files (MuJoCo scenes, mesh swap, fram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
    [banana_pcb_locker.stl, bearing_roll.stl, leg.stl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]
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2026-09-02 rebuild round 2: ankle, thigh, foot, neck, hip links verified; trunk-base connector name swap fixed (verify agent's finding); electronics datasheet folders; wiring part records
    [bom-priced-rung6.csv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]
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2026-09-02 neck proof + true-colour fix: head_sweep.py drives the 4 head command slots and MEASURES each joint (neck_pitch 16°, head_pitch 38°, head_yaw 67°, head_roll 22°) — the 'stiff neck' was zero head comm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
    [ours.stl]
2026-09-02 SIM-CAPABILITY.md §1-2: our stack vs SolidWorks, measured; MuJoCo runs Pollen's policies 77x real time; robotd-in-the-loop is the bounded missing piece
    [ours.stl]
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2026-09-02 SIM-CAPABILITY.md — our stack vs SolidWorks, measured; MuJoCo runs Pollen's policies 77x real time; robotd-in-the-loop (Dynamixel register model backed by mj_step) is the bounded missing piece; Isaac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
    [microduck_robot_hat.kicad_pcb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]
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2026-09-02 RELEASE.html — the real release dossier: professional light academic/datasheet styling (no dark, no pills), honest readiness matrix (PROTOTYPE not factory-ready + what blocks factory), BOM, file inde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
    Leif: 'a real full release document ... step by step assembly of all parts and
    joints and everything ... with all wiring ... in one document' + 'completely
    factory ready' (answered honestly: prototype-ready, 3 named blockers) + kill the
    AI-slop dark styling. Every claim links to a real repo file.
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2026-09-02 microduck: photo-vs-CAD reference-match dossier + clean MuJoCo assembly steps
    - COMPARISON.html: our CAD posed at the STAND keyframe, shot at the same
    camera angles as the official Pollen product photos, side by side. Honest
    verdict: geometry same by construction (Pollen's meshes, rebuilds graded
    <=1mm), colour is schematic sim material (not product paint), pose/lens close.
    - sim/compare_render.py: MuJoCo studio renderer (white sky, no floor), remaps
    each rebuilt __ours part to its real product material, PHOTO pose (gentle
    head), 8 orbit angles + 4 joint close-ups (proof the rig is reused, instant).
    - sim/assembly_steps_mj.py: replaces the meshview step renders that z-fought
    ('st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
    [microduck-ankle-left.step, microduck-hip-bracket.step, microduck-shin.step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]
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2026-09-02 microduck: correct the head finding — measurement overrides the eyeball
    The visual impression was that the sim head is markedly longer front-to-back
    than the product head. tools/head_analysis.py measures scale-free silhouette
    ratios and says otherwise: head length / robot height agrees to 3.76%
    (product 0.4233, ours 0.4392). The aspect ratio does differ by +69%, but that
    comparison is confounded — the reference photograph has the beak OPEN and the
    head TILTED, both inflating the product's apparent head height.
    Verdict downgraded from 'critical mismatch' to CANNOT DETERMINE, with the two
    routes that would settle it stated (re-pose the jaw, or photogrammetric scaling
    against the XL330's k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
    [microduck-shin.step, microduck-upper-leg-left.step]
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2026-09-02 GOAL.md: handover corrections — head finding is CANNOT DETERMINE (settle by XL330-scaled photogrammetry first), electronics verification results captured in out/handover/, FEA matrix + manufacturing 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
2026-09-02 workflows: rename handed-over scripts to unambiguous names
    w7-/w8-/w5-/w4- collided with four pre-existing scripts in this directory. The
    two that must be relaunched after the handover are now elec-verify.js and
    manufacturing.js, which cannot be confused with w7-ce-cad-viewer.js,
    w5-manufacturing.js, w4-wiring.js or w4-simulate's predecessor.
2026-09-02 electronics: rescue and commit the elec-verify workflow results
    Workflow wf_969f3a4c-3d1 completed (15/15 agents, 0 errors, 891k tokens) as this
    session was being handed over. Its structured output is rebuilt from the run
    journal into out/verify/electronics_verify.json and the journal itself is kept
    as the audit trail.
    11 components + 3 custom boards; 22 line items, 2 VERIFIED / 10 PARTIAL /
    10 CANNOT DETERMINE. Electronics BOM $465.64 at qty 1; qty-100 unresolved
    because the dominant line has no published volume price.
    Design-affecting findings recorded in workflows/RUNNING.md:
    - XL330 servos may be fed ~6.6-8.2 V from the raw 2S pack against a 3.7-6.0 V
    datasheet rating; needs a meter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
    [microduck-upper-leg-left.step]
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2026-09-02 out/stress/matrix.json: detached FEA matrix finished — 4 parts x 3 load cases PLA: ankle landing SF 0.674 FAIL at 60 N, shin/hip-bracket PASS, upper-leg CANNOT DETERMINE at every gmsh size down to 0.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
    [microduck-ankle-left.step, microduck-hip-bracket.step, microduck-upper-leg-left.step]
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2026-09-02 lane T: connection:press-fit-tube-15 — the Ø15.0 x 149.06 deg arch cradle measured off motor_support.stl, coaxial to 0.0005 mm with the jaw's Ø10.0000 journal; the 'lens seat' reading refuted by meas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
2026-09-02 lane G: six assembly jigs as cecad parts with verified A3 drawings — four bearing pushers (the boss seats need INNER-ring pushers, which the assembly text gets wrong), XL330 horn index gauge, press a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
    [microduck-jig-horn-zero.dxf, microduck-jig-horn-zero.stl, microduck-jig-press-15-inner.dxf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]
2026-09-02 F2: battery runtime from the measured MuJoCo torque/speed profile through ROBOTIS's published XL330 stall and no-load rows; compute draw stays CANNOT DETERMINE and is swept
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2026-09-02 lane T: connection:snap-fit-ankle-blocks — blocks 5.0000x4.0000 in through-pockets 5.2000x4.2000 (0.1000 mm/side, pitch 26.8000) on an R16.3018 cradle; measured finding: nothing snaps, the foot is M2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
2026-09-02 release: link TEST-PLAN.html (TOC, readiness row, section 6) and correct the servo-VDD assertion in the power-up steps
    Section 6 step 1 stated 'Servo-bus VDD is battery-direct through the HAT' as
    fact. It is an inference from model.rs:99-113, not a measurement, and the XL330
    shelf record (part:xl330-m288-t supplies[0]) states the conflict explicitly:
    vendor band 3.7-6.0 V against a 6.6-8.2 V pack read through that very pin.
    Restated as CANNOT DETERMINE with TEST-PLAN EB-04 named as the measurement.
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2026-09-02 lane T: connection:snap-fit-roller-axle — the foot's barbed fingers measured by height (lead-in 36.0890 -> barb land 34.7000 -> pocket 36.7000) and identified by measurement as snapping over the ankl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
2026-09-02 F3: measure head/trunk cavity volumes, per-hinge joint geometry, and the 14-hinge tolerance stack-up (bearing seats grade coarser than IT15 at every published FDM band)
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2026-09-02 lane C: measure the Radxa ZERO 3W mount frame off its own drawing; close finding 2 (battery is NP-F550, not F970) by measuring the bay
    Radxa publishes no DXF and no STEP; product-brief section 4 is a raster. tools/measure_radxa_drawing.py
    measures it sub-pixel and carries four negative controls that a wrong scale fails (the 2x20 header
    body must come out 5.08 x 50.80 mm and its centre 3.3 / 32.4 mm from the edges, which Radxa prints).
    4/4 PASS. Mount holes: 4 x O2.8140 mm, edge inset 3.5727 (Radxa prints 3.6), pitch 57.8429 x 22.8662.
    That corrects part.py's RADXA_LONG_SPAN = 54.7 -- a by-eye misread of a connector dimension that would
    have missed all four holes by 1.57 mm; recorded as a fai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
2026-09-02 F3 thermal: locate the compute in the HEAD (not the trunk), measure the enclosure and show the failing leg is die-to-skin, not skin-to-room
2026-09-02 lane T: assembly:microduck joints.json re-seeded — 14 of 14 hinges resolved on both sides, every one 0.000 mm off axis (4 brackets found in the parent body); assembly.json verdict corrected from the 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
2026-09-02 legs: sweep every leg joint through its MJCF range and measure it — travel, peak velocity, tracking, and MuJoCo self-collision onsets to 0.1 deg (out/motion/legs.json)
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2026-09-02 sim: MuJoCo-measured load basis (measure_loads.py), drop-impact model comparison, fatigue on the ankle with the Ezeh & Susmel 2019 design curve, FEA runner on every structural part (stress_all.py); s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
2026-09-02 lane C: close four open CANNOT DETERMINEs to verdicts, and correct two wrong inferences
    ToF generation: not one answer -- BOTH. Pollen's own driver doc (tof/src/lib.rs) says the L5CX and
    L8CX are interchangeable, decided at runtime by an ID read, and that ducks in the field carry both.
    That forces a requirement nobody had written down: the L8CX's IOVDD absolute max is 1.98 V and the
    L5CX supports 3.3 V, so a socket taking either cannot present the HAT's 3.3 V I2C directly -- the
    breakout must regulate and level-shift.
    Mic: 'Mic3R' is not a pin. TI's SLAS510G has no MIC3 anywhere; the Linux tlv320aic3x driver names the
    same register and bit 'Mic3R' generically and 'Mic2R' for the AIC3104, an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
2026-09-02 lane D: imu_to_dxl and banana-contact boards captured, HAT outline corrected from Pollen's own mesh
    - electronics/imu-to-dxl/board.py: LSM6DSV16X + STM32G031F6P6 + 74LVC1G125 +
    LP2985A-33DBVR on 34.000 x 24.000 mm, three JST B3B-EH-A bus ports.
    Decisions E1-E9, each with the option it beat. LGA-14L land pattern read
    off DS13510 Rev 4 Figure 33 (p.175/198) at 200 dpi; TSSOP20 pin numbers off
    DS12992 Rev 4 Figure 5 (p.32/126).
    - electronics/banana-contact/board.py: 45.800 x 5.100 mm contact strip sized
    to the pocket MEASURED in power_support.stl (45.860 x 5.150 x 8.000 clear).
    Contact pitch 4.000 is DERIVED from the 12.000 mm window, not measured off
    a pack, and says so everywher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
2026-09-02 F3: solver self-test with a watched negative control (radiation sign flipped, three checks went red, restored)
    [thermal-servo-xl330.json]
2026-09-02 legs: break the self-collision detector on purpose and watch it fire (negative + two positive controls) before trusting any CLEAR; note the MJCF actuator is 1.846x the cited XL330 stall torque and ca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
2026-09-02 drawings: the generator driver, the print-sheet path, the tolerance basis and the index
2026-09-02 F2: 37-cell gait sweep at 200 Hz with path length, yaw drift and forward-tracking ratio; per-family videos read back; F2 section generator
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2026-09-02 stress: FEA matrix completed — the ankle fails the landing case in every material
    12 solves (4 structural parts x 3 load cases in PLA) plus mesh convergence and
    a 5-material sweep, from the detached sim/stress_matrix.py run.
    Governing result: microduck-ankle-left under the 60 N landing case (3x
    bodyweight on one leg) gives SF 0.674 — a predicted yield. The material sweep
    shows this is not a material problem: PLA 0.674, PETG 0.648, ABS 0.534,
    NYLON 0.971, ASA 0.587. Every candidate is below 1.0, so substituting filament
    does not clear it; it needs a geometry change, a lower design load, or an
    explicit decision to treat the ankle as sacrificial.
    Two honest limits recorded rather than bur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
    [microduck-ankle-left.step, microduck-ankle-left.stl, microduck-ankle-right.stl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]
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2026-09-02 lane D: the banana board's pocket was measured with the wrong ceiling
    Ray-cast the power_support solid on a 2 mm grid at y = 31.000, mid-gap, instead
    of reading section outlines. The map is unambiguous: above z = 51.000 the only
    material is the two screw posts at x = +/-25, so the pocket is OPEN UPWARD and
    the head plate is BEHIND the board, not above it. The plate's top edge is also
    curved - 56.944 mm at x ~ +4, 55.51 at x +/-24 - so no single number off one
    section was ever the ceiling, and the 56.080 read at x = 20 was an artefact of
    where the section was taken.
    The real ceiling is the locker bar's own silhouette, z 48.974..55.626: a board
    taller than its retainer is a board the retainer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
    [microduck_banana_contact-bom.csv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]
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2026-09-02 F3 fix: servo thermal graded across every ambient it carries (35 degC puts left_knee over the limit — the empty list was a 25 degC-only read) and across every duty cell, not just the vx=0.25 baseline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
    [thermal-servo-xl330.json]
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2026-09-02 lane E fix: out/release/bom.csv is generated from spec/sourcing.json instead of hand-written — it had drifted to CANNOT DETERMINE on B14 and B8 (both PASS) and to beaten prices on B9 and B6, so the d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
    [bom.csv]
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2026-09-02 lane F1 fix (skeptic 16): commit the solver decks the report.json values were reduced from — shin walk/drop and yaw2roll drop re-solved 2026-09-03 02:41-02:44 and reproducing the committed peaks to 6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
    [microduck-ankle-left.step, microduck-shin.step]
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2026-09-02 lane F1 fix (skeptic 1-7, 10-13, 15): publish all 32 studies incl. the four head-drop cases — the '_h' filter matched *_head_drop and no sub-run; one grading rule for every study (sim/fea_rejudge.py 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
    [fea_microduck-motor-support_drop.json, fea_microduck-motor-support_head_drop.json, fea_microduck-motor-support_walk.json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]
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2026-09-02 lane D: imu_to_dxl routed 40/53 with three named open nets, and the stub trade-off is measured
    Three runs on the same layout, same budgets, only the GND stub vias changing:
    10 stubs -> 43/53 routed, 7 FAIL (two 'hole-to-hole via GND / via GND' and a
    GND track 0.000 mm from U4.1)
    9 stubs -> 45/53 routed, 5 FAIL
    0 stubs -> 40/53 routed, 3 FAIL, every one of them 'unrouted'
    The stubs buy routed connections and pay for them in fixed obstacles on a
    40 x 22 mm board carrying 24 parts. The version shipped is the 0-stub one:
    fewer rule violations and no clearance or hole-to-hole defects, only open
    connections - GND 8, V3V3 5, IMU_INT1 1.
    PCB-PACKAGE.html section 5.9 carries th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
    [microduck_imu_to_dxl-B.Cu.GBL, microduck_imu_to_dxl-B.Mask.GBS, microduck_imu_to_dxl-Edge.Cuts.GKO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]
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2026-09-02 lane F1 fix (skeptic 10, 12, 16): the geometrically nonlinear re-solves land — motor-support drop 173.180 MPa (0.947x linear, the linear 0.273 stays as the more conservative), rigidity plate walk 61.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
    [fea_microduck-motor-support_drop.json, fea_nlgeom_microduck-motor-support_drop.json, fea_nlgeom_microduck-motor-support_head_drop.json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]
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2026-09-02 lane D: both boards re-routed with the measured fixes; Robot HAT 10 FAIL -> 8
    Robot HAT, 44 pass / 8 fail / 3 cannot determine: the three 0.000 mm clearance
    rows the i2s3/DIN spine used to produce are GONE - it now leaves J1 pad 40,
    which is the pin that actually carries that net (Radxa brief RAD-DOC-0084: pin
    40 GPIO3_A5 I2S3_SDO_M0) - and i2s3/BCLK now routes. What is left is one
    hole-to-hole via/via and seven open nets. Widening VBAT / SERVO_V / V5_HAT
    from 0.400 to 0.800 mm bought copper capacity (1.231 A -> 2.034 A at dT 10)
    and cost two routes.
    imu_to_dxl, 36 pass / 3 fail / 3 cannot determine, 40/53 routed: every
    remaining failure is 'unrouted' - no clearance, no hole-to-hole, no cou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
    [microduck_robot_hat.kicad_pcb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]
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2026-09-02 lane G fix: jig sheets get the required isometric reference view, and the horn gauge's two pins are dimensioned on their own drawing
    docs/MANUFACTURING-REQUIREMENTS.md A.4 requires a dimensioned isometric
    reference view on every sheet. All six jig sheets shipped without one
    (measured: grep -ci ISOMETRIC = 0 on all six SVGs). tools/jigs.py now calls
    auto_blueprint(manufacturing=True), which is what puts the isometric, every
    radius, the detail bubbles and the print/DFM note block on the paper — all six
    now read isometric_on_sheet true, verify_sheet PASS, A2.
    microduck-jig-horn-zero carried NO diameter or PCD callout at all: its two
    index pins are ADDITIVE bosses, so inspect.holes() returns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
    [microduck-jig-horn-zero.dxf, microduck-jig-press-15-inner.dxf, microduck-jig-press-15-outer.dxf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]
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2026-09-03 lane E fix (skeptic 1,2,3,5,6): the three custom PCBs are QUOTED from this repo's own committed fab packages, the two-distributor guard can go red, and the dossier's sourcing numbers are generated ra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
    1. P1/P2/P3 were refused on a premise the repository contradicted ('There is nothing to send a fab'). All three fab zips were already committed (077fe49, e63dd4f). Every board number is now MEASURED off the committed .kicad_pcb and Edge.Cuts.GKO and re-verified independently this pass: robot_hat 1759 copper segments (879 at 0.1500, 803 at 0.3000, 61 at 0.8000, 10 at 0.2500, 4 at 0.2000, 2 at 0.4000), 33 vias 0.800/0.300, 97 drilled holes, outline 65.0000 x 30.0000 mm; imu_to_dxl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
    [bom.csv]
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2026-09-03 checkpoint: artifacts written by the five workflows that were killed by the 2026-09-03 18:47 restart
    Not a verified state. Every agent in microduck-sheet-rebuild, -pose-match-wiring,
    -harness-cad-joints, -every-fastener and -resolve-unknowns died in its FIRST phase
    (journals hold 'started' rows and no 'completed' row for any of the 19 agents), so
    these files are partial output from interrupted runs and are committed only so the
    restart has a baseline it can diff against, per the standing rule that out/ is
    committed. The restarted workflows regenerate all of it.
    116 files under out/drawings (sheetcheck-edges/-solid probes and re-rendered sheets
    from the Instrument phase), 9 out/stress, 5 out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
    [microduck-ankle-left.dxf, microduck-ankle-left.step, microduck-ankle-right.dxf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]
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2026-09-03 resolve-servo lane (partial checkpoint 1) OWNS out/open/servo-electrical.json, out/open/servo-joint-sides.json, out/open/servo-electrical-evidence/, ce-parts/xl330-m288-t/, tools/servo_joint_sides.py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
    [ASE01187-C1_elec_RPI_Robot_HAT_BOM.csv, servo-joint-sides.json]
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2026-09-03 resolve-identity (class 5) checkpoint 1, PARTIAL: owns out/open/identity-sourcing.json, out/open/identity-evidence/, ce-parts/microduck-{speaker,mic,camera-module,tof-module}/, ce-parts/radxa-zero-3w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
    [ASE01187-C1_elec_RPI_Robot_HAT_BOM.csv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]
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2026-09-04 internals build2 FINDING, settled by measurement: the Robot HAT in our CAD is a development revision Pollen NEVER PRODUCED. Pollen's simulation mesh matches commit fbd885d — the layout immediately be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
    [0r-r-0402-1005metric.step, 1-3a-600r-100mhz-l-0402-1005metric.step, 100n-50v-c-0402-1005metric.step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]
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2026-09-04 checkpoint after the 22:25 crash: work the killed lanes had written to disk (fastener raw measurements, hat PCB, wiring, eye-ring sheet, tools)
    [robot-hat-pcba.step]
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2026-09-04 internals build2 checkpoint 4 — THE LIBRARY IS CORRECT ON DISK, AND THE CHECK THAT PROVES IT. LIBRARY READ-BACK over 53 exported files: 0 disagree with the shape in memory (was 53 of 53). ROUND TRIP 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
    [0r-r-0402-1005metric-bottom.step, 0r-r-0402-1005metric-top.step, 0r-r-0402-1005metric.step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]
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2026-09-04 internals build2: replace robot-hat-pcba.step with the one built by the corrected tool, and drop three stale PNGs.
    The tracked copy of the STEP was written at 22:20 by the run whose round trip was 58.600000 mm and whose bodies spanned 154.875 x 124.863 mm for a 65.000 x 30.900 mm board - a 14.8 MB file that is wrong in every component position and that looks entirely normal to anything that merely opens it. The new one is the 112-body board at the manufacturer's own pick-and-place positions, written through Shape.exportStep for the same reason the component library is (ce-cad F84: Import.export silently drops a shape's placement).
    Also removes pcba-iso.png, pcba-top-BROKEN.png and pcba-iso-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
    [robot-hat-pcba.step]
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2026-09-04 own-geometry lane, head-shells group: checkpoint the eye-ring parametric rebuild as it stands on disk — part.py is a solid of revolution from ten caliper readings (tools/own_measure_eyering.py, out/o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
    Claude-Session: https://claude.ai/code/session_016TL4NsUTzdp9LvLdTfqCqU
    [ours.stl]
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2026-09-05 microduck: X1C plates, a packer that refuses to overflow, and a sourcing pack
    The sliced plates target a Bambu H2S (340x320). The machine on the LAN is an X1
    Carbon (256x256) and returns BambuStudio -52, "objects located over the boundary
    of the heated bed". Re-plated for the real machine.
    tools/plate_for_printer.py: bin-packs by footprint, slices, and ON -52 SPLITS the
    group and retries rather than emitting a plate that cannot print. Two parts refuse
    auto-orient (top-head-shell, yaw-roll-motion - the latter already recorded in
    PRINT.md as crashing auto-orient); both slice as modelled, alone.
    TPU re-sliced at 85A after the first pass silently took the X1C's 90A default.
    The soles and soft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
    [lcsc-bom.csv, microduck-PLA-X1C-01.3mf, microduck-PLA-X1C-02.3mf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]
2026-09-05 microduck: head plates for the two real machines, and the slicer driven properly
    plate_for_printer.py now delegates BOTH documented ce-slice fixes instead of
    reimplementing the CLI call:
    1. presets are FLATTENED through ce_slice.presets().flatten(). Handing the CLI a
    leaf preset gives filament_density=0 - ce_slice.py's header calls that "the
    entire root cause of every 0.00 g slice on this machine" and I had reproduced
    it exactly: six plates with tray_info_idx="" and used_g="0.00".
    2. curr_bed_type comes from ce_slice._bed_type(filament), which reads the plate
    temperatures out of the filament preset. Without it PETG is refused with
    return_code -61 "Filaments are n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
    [head-A.3mf, head-big-orange.3mf, head-x1c-B.3mf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]
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2026-09-08 microduck: HEAD v4 — validated, not sent. meshfix'd meshes (stl/fixed), what the validator found in the earlier sends, the standard workflow
    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
    [HeadAll.3mf, microduck-ankle-left.stl, microduck-ankle-right.stl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]
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2026-09-08 Reconcile public HAT clock and rails and correct bundled lead quantities
    [bom.csv]
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2026-09-08 Resolve modeled fastener endpoints and preserve unverified thread identity
    [per-line.csv]
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2026-09-08 Correct conditional component fit and whole-package sourcing quantities
    [bom.csv, conditional-rfq.csv]
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2026-09-08 Correct: the 帆哥 video and replica are real (friend of a friend); poster is promo art, repo is the source
    Claude-Session: https://claude.ai/code/session_01J8PNrAqMMXfJZwCUotfer7
    [HeadAll.3mf, microduck-shin.dxf]
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2026-09-09 fit: vendor XL330 solid substituted in memory for every servo (rest census rerun), ankle mirror grade, servo parenting audit, coupled-trajectory poser; fix sweep onset bookkeeping (+ side was overwri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
    - tools/fit_vendor_servo.py build|rest: vendor STEP fused one solid at a time with
    a per-step volume check (multiFuse lost 60% of the volume), MeshPart 0.1 mm/30 deg
    -> 13314 closed triangles; frame local=(vendorZ+8, vendorX, vendorY) proven by
    horn/idler disc fits (0.00-0.41 deg, 0.00-0.04 mm) and by every driving hinge
    (0.087 mm off-axis, 0.0 deg). Rest census with it: out/fit/rest-vendor-servo.json,
    15 of 16 above-0.3 mm pairs survive; the six 4.3-4.5 mm servo-seat hits be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
    [rest-vendor-servo.json, servo-parenting.json, vendor-servo-frame.json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]
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
